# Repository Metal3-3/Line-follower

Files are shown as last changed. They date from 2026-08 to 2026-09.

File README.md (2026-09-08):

# Line follower robot STARK-F1
Line_Follower

My first ever serious project. STARK-F1 is a line follower robot that uses arduino nano as the micro controller. I wanted to make this after seeing how much line follower kits cost. This robot can be set to faster speeds and can be used in competitions. Right now its set to 70 speed (out of 255) so with proper changes it can be way faster and complete parkours.

# Main components
lfstrak

# Performance

- Sensor: QTR-8A
- Controller: Arduino Nano
- Motor Driver: TB6612FNG
- Control Algorithm: PID
- Motors: 12V 1200 RPM
- Battery: 2S Li-Po
- Wheel Diameter: ~40 mm
- Chassis: 171 × 112 × 4 mm

# softwares
- tinkercad 
- online ide/compilers
- arduino ide

# chassis info
it has been designed in tinkercad with the wheels, motor holders, and silicone wheel mold
i designed it getting inspriation from other line follower robots and from my knowledge. The hardest part was designing the mold pretty much. The chassis uses m3 holes (3mm) with 4 holes on side for the motor holder, 4 on the front for the qtr-8a and 4 in the middle for the arduino uno shield.
The diameters are 112 x 171 x 4

# Code info
i got help with claude ai in the code. Through the code i used turkish for the different variables and even the names. 
Main.ino is the main file that includes the main variables and calibration. 
MotorKontrol.ino is for motor controll, 
Sensoroku.ino is for reading the sensor. 
SensorOkuYaz is to read the sensor and output it. 
## Main.ino
tabanhız is the main speed and right now it is 70. İf you want it faster you might have to change kp and kd (pid variables.)
ekhız is add on speed right now 0 and not bing used it will be relevant once i update the code for it to be fast and accurate.

## License

### Code
MIT License

### 3D Models
CC BY 3.0

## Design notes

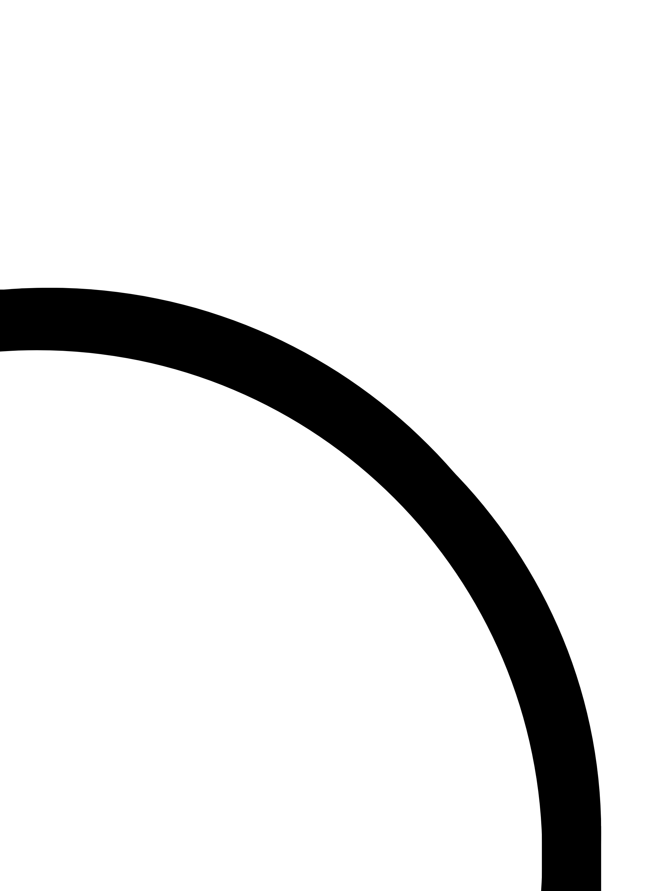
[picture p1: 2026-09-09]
Line Map/LeftCurvingLine.png

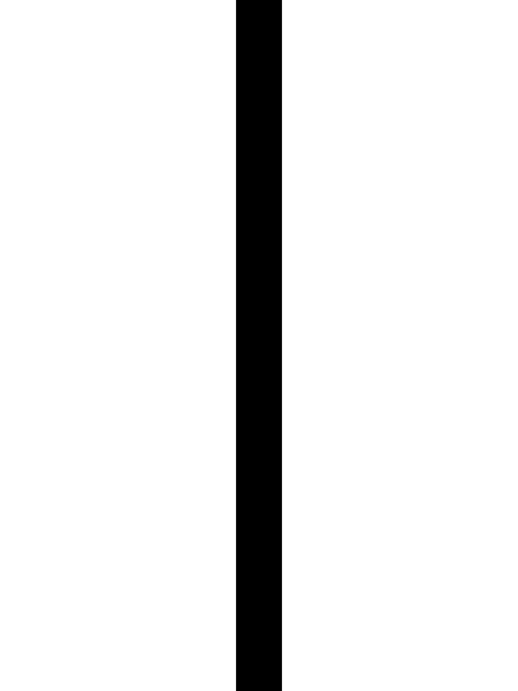
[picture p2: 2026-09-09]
Line Map/StraightLine.png

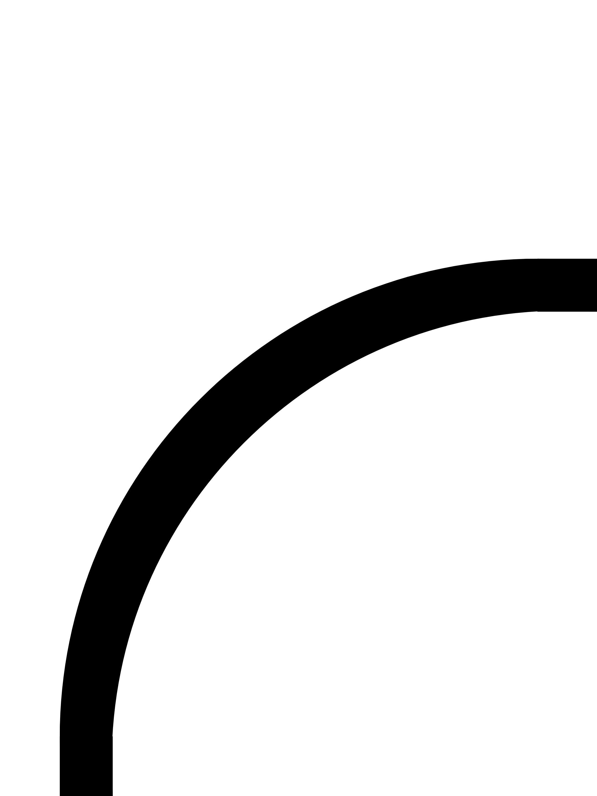
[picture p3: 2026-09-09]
Line Map/RightCurvingLine.png

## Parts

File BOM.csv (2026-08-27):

Source: robotistan.com/sepet cart | FX rate used: 1 USD = 48.09 TRY
No | Part Name (English) | Part Name (Turkish) | Brand | Qty | Unit Price (TL) | Unit Price (USD) | Total Price (TL) | Total Price (USD)
1 | QTR-8A 8-Channel Line Following Sensor Array | QTR-8A 8'li Çizgi Algılama Sensör Kartı | Robotistan | 1 | 116,00 TL | $2,41 | 116,00 TL | $2,41
2 | 6V 12mm 600 RPM Micro Metal Gear DC Motor | 6V 12mm 600 RPM Redüktörlü DC Motor | Robotistan | 2 | 184,54 TL | $3,84 | 369,08 TL | $7,67
3 | Arduino Nano Development Board (CH340) | Arduino Tabanlı Nano Geliştirme Kartı (CH340) | Robotistan | 1 | 243,12 TL | $5,06 | 243,12 TL | $5,06
4 | Nano Sensor Shield for Arduino | Arduino için Nano Sensor Shield | Robotistan | 1 | 84,95 TL | $1,77 | 84,95 TL | $1,77
5 | Mini Caster Wheel Plastic - 2 Pcs | Mini Sarhoş Teker Plastik - 2 Adet | Robotistan | 1 | 43,94 TL | $0,91 | 43,94 TL | $0,91
6 | 40-Pin Female-Male Jumper Wires - 200mm | 40 Pin Ayrılabilen Dişi-Erkek M-F Jumper Kablo - 200 mm | Robotistan | 1 | 55,07 TL | $1,15 | 55,07 TL | $1,15
7 | TB6612FNG Stepper/DC Motor Driver | TB6612FNG Step Motor Sürücü / DC Motor Sürücü | Robotistan | 1 | 118,34 TL | $2,46 | 118,34 TL | $2,46
8 | SLT20 Silicone Wheel (33x21mm) - 2 Pcs | SLT20 Silikon Tekerlek (33x21 mm) - 2 Adet | Jsumo | 1 | 473,36 TL | $9,84 | 473,36 TL | $9,84
9 | M3 Hex Nut | M3 Somun | Robotistan | 50 | 0,96 TL | $0,02 | 48,00 TL | $1,00
10 | 25mm M3 Female-Male Standoff Spacer | 25 mm M3 Metal Dişi-Erkek Aralayıcı (Standoff-Spacer-Yükseltici) | Robotistan | 4 | 9,37 TL | $0,19 | 37,48 TL | $0,78
11 | M3 10mm Phillips Round Head Machine Screw | M3 10 mm YSB Yıldız Silindirik Bar Metrik Vida | Robotistan | 25 | 0,82 TL | $0,02 | 20,50 TL | $0,43
12 | LM2596 Mini Adjustable Buck Converter Module 3A (4-35V to 1.25-30V) | LM2596 Mini Ayarlanabilir Voltaj Düşürücü Regülatör Kartı 3A (4-35V ile 1.25-30V) | Robotistan | 2 | 60,93 TL | $1,27 | 121,86 TL | $2,53
13 | Aspilsan INR18650A28 3.7V 2800mAh Li-ion Rechargeable Battery - Flat Top | Aspilsan INR18650A28 3.7V 2800 mAh Li-ion Şarjlı Pil - Kutup Başsız | Aspilsan | 2 | 189 TL | $3,93 | 378 TL | $7,86
14 | 2s 2a Type-C Lipo Charge Module-4878 | 2s 2a Type-c Lipo Şarj Modülü-4878 | - | 1 | 111,78 TL | $2,32 | 111,78 TL | $2,32
15 | 18650 2 Battery Holder | 18650 İkili Şarj Yuvası | Robotiko | 1 | 65 TL | $1,35 | 65 TL | $1,35
16 | 2s 3a 7.4V bms Charge Protector | 2s 3a 7.4v bms Şarj Koruma kartı | - | 1 | 69,48 TL | $1,44 | 69,48 TL | $1,44
TOTAL |  |  |  |  | 1.826,66 TL | $37,97 | 2.355,96 TL | $48,98

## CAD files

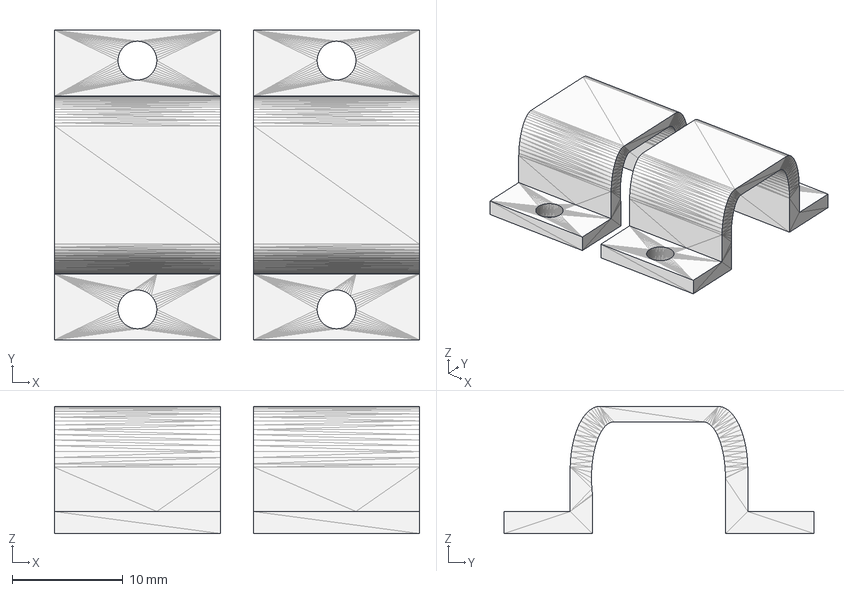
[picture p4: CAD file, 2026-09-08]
3D Files/Motor holder 2.step
33.0 x 28.0 x 11.5 mm

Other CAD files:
3D Files/Chassis 2.step

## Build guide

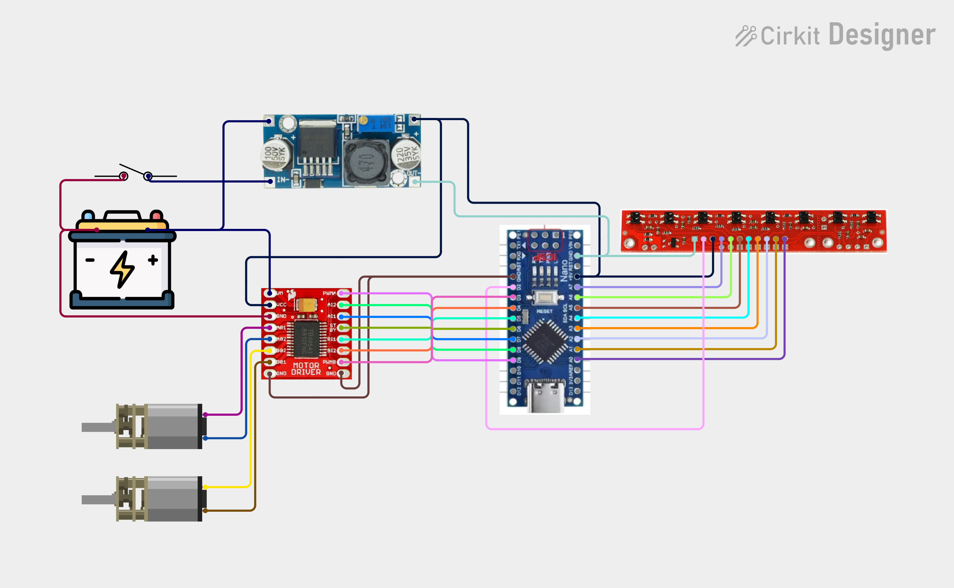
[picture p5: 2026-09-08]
Wiring/circuit_image(2).png

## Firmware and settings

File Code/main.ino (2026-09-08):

#include <QTRSensors.h> //Yeni Pololu QTRSensors kütüphanesi

#define sagmotor2 4
#define sagmotor1 5
#define sagmotorpwmpin 3
#define solmotor2  8
#define solmotor1  7
#define solmotorpwmpin  9
#define STBY 6
#define LED 2

QTRSensors qtra;
uint16_t sensors[8];
float Kp = 0.04;  
float Kd = 0.03;
int tabanhiz=70;       
int ekhiz = 0;
int sonhata = 0;
int hata = 0;
int sagmotorpwm = 0;
int solmotorpwm = 0;
int zemin = 0;
int kalibrehizi = 90;
int sagcataldurum=0;

void setup() {
  Serial.begin(9600);
  qtra.setTypeAnalog();
  qtra.setSensorPins((const uint8_t[]) {A7, A6, A5, A4, A3, A2, A1, A0}, 8);
  qtra.setSamplesPerSensor(8); // gürültüyü azaltmak için örnek sayısını artır (varsayılan 4)

  pinMode(sagmotor2, OUTPUT);
  pinMode(sagmotor1, OUTPUT);
  pinMode(sagmotorpwmpin, OUTPUT);
  pinMode(solmotor2, OUTPUT);
  pinMode(solmotor1, OUTPUT);
  pinMode(solmotorpwmpin, OUTPUT);
  pinMode(LED, OUTPUT);
  digitalWrite(LED, HIGH); // QTR-8A IR LED'lerini kalıcı olarak AÇIK tut — bir daha KAPATMA
  pinMode(STBY, OUTPUT);
  delay(1500);

  digitalWrite(STBY,1);//MOTOR SÜRÜCÜ 1 AKTİF, 0 PASİF

  for (int i = 0; i < 150; i++)
  {
    if (0 <= i && i < 5) motorkontrol(kalibrehizi, -kalibrehizi);
    if (5 <= i && i < 15) motorkontrol(-kalibrehizi, kalibrehizi);
    if (15 <= i && i < 25) motorkontrol(kalibrehizi, -kalibrehizi);
    if (25 <= i && i < 35) motorkontrol(-kalibrehizi, kalibrehizi);
    if (35 <= i && i < 45) motorkontrol(kalibrehizi, -kalibrehizi);
    if (45 <= i && i < 55) motorkontrol(-kalibrehizi, kalibrehizi);
    if (55 <= i && i < 65) motorkontrol(kalibrehizi, -kalibrehizi);
    if (65 <= i && i < 75) motorkontrol(-kalibrehizi, kalibrehizi);
    if (75 <= i && i < 85) motorkontrol(kalibrehizi, -kalibrehizi);
    if (85 <= i && i < 95) motorkontrol(-kalibrehizi, kalibrehizi); 
    if (95 <= i && i < 100) motorkontrol(kalibrehizi, -kalibrehizi); 
    qtra.calibrate(); delay(1);
    if (i >= 100) {
      motorkontrol(0, 0);
      delay(3);
    }
  }

  // --- DEBUG: kalibrasyon çalışmış mı kontrol et ---
  Serial.println("Kalibrasyon MIN:");
  for (uint8_t i = 0; i < 8; i++) {
    Serial.print(qtra.calibrationOn.minimum[i]);
    Serial.print('\t');
  }
  Serial.println();
  Serial.println("Kalibrasyon MAX:");
  for (uint8_t i = 0; i < 8; i++) {
    Serial.print(qtra.calibrationOn.maximum[i]);
    Serial.print('\t');
  }
  Serial.println();
  // --- DEBUG SONU ---
}

void loop() {
 sensoroku();
 pid();
 motorkontrol(solmotorpwm,sagmotorpwm);

 // --- DEBUG: pozisyon, hata ve ham sensör değerlerini izle (sorun çözülünce sil) ---
 sensorlerioku_yaz();
 Serial.print("hata: ");
 Serial.print(hata);
 Serial.print("\tsol pwm: ");
 Serial.print(solmotorpwm);
 Serial.print("\tsag pwm: ");
 Serial.println(sagmotorpwm);
}

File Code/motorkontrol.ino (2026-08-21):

void motorkontrol(int solmotorpwm,int sagmotorpwm){   //Örnek: motorkontrol(-50,50);
if(solmotorpwm<=0){
  solmotorpwm=abs(solmotorpwm);
  digitalWrite(solmotor2,LOW);
  digitalWrite(solmotor1,HIGH);
  analogWrite(solmotorpwmpin,solmotorpwm);
}
else{
  digitalWrite(solmotor2,HIGH);
  digitalWrite(solmotor1,LOW);
  analogWrite(solmotorpwmpin,solmotorpwm);
}

 if(sagmotorpwm<=0){
  sagmotorpwm=abs(sagmotorpwm);
  digitalWrite(sagmotor2,LOW);
  digitalWrite(sagmotor1,HIGH);
  analogWrite(sagmotorpwmpin,sagmotorpwm);
 }
 else{
  digitalWrite(sagmotor2,HIGH);
  digitalWrite(sagmotor1,LOW);
  analogWrite(sagmotorpwmpin,sagmotorpwm);
 }
}

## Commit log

2026-08-14 Rename Motor holders.stl to stl files/Motor holders.stl
    [Motor holders.stl]
2026-08-14 Rename chassis.stl to stl files/chassis.stl
    [chassis.stl]
2026-08-14 Rename wheel mold.stl to stl files/wheel mold.stl
    [wheel mold.stl]
2026-08-14 Rename wheels.stl to stl files/wheels.stl
    [wheels.stl]
2026-08-21 Rename circuit_image (1).png to Wiring/circuit_image.png
2026-08-21 Added codes for PID, motor control, sensor read
    and also some code to flash the robot if needed
2026-08-25 Rename Motor holders.step to STL/Motor holders.step
    [Motor holders.step]
2026-08-25 Rename Wheel Mold.step to STL/Wheel Mold.step
    [Wheel Mold.step]
2026-09-08 Rename Chassis 2.step to 3D Files/Chassis 2.step
    [Chassis 2.step]
2026-09-08 Rename Motor holder 2.step to 3D Files/Motor holder 2.step
    [Motor holder 2.step]
2026-09-08 Rename circuit_image (2).png to Wiring/circuit_image(2).png
